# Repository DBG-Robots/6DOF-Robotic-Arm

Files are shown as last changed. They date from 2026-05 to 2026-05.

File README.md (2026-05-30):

# 6DOF Robotic Arm

A 6 degree-of-freedom robotic arm built from scratch. The project covers the full hardware and software stack: a custom STM32-based motor controller PCB, 3D-printed mechanical structure, and embedded firmware.

---

## Project Status

| Area | Status |
|---|---|
| Schematic | Complete |
| PCB Layout | In progress |
| STM32CubeMX pin assignment | Complete |
| Firmware | Not started |
| 3D Design | Not started |

---

## Repository Structure

```
.
├── LICENSE
├── PCB/
│   ├── Arm_Controller.kicad_sch       # Top-level schematic
│   ├── MCU.kicad_sch                  # STM32G431CBT6 schematic sheet
│   ├── Drivers.kicad_sch              # TMC2209 driver schematic sheet
│   ├── Power.kicad_sch                # Power supply schematic sheet
│   ├── Connectors.kicad_sch           # Connector schematic sheet
│   ├── Indicator.kicad_sch            # LED indicator schematic sheet
│   ├── Arm_Controller.kicad_pcb       # PCB layout
│   ├── Arm_Controller.kicad_pro       # KiCad project file
│   └── hardware/                      # Datasheets and reference material
└── STM32Cube/
    ├── Core/                          # Generated HAL application code
    ├── Drivers/                       # STM32 HAL and CMSIS drivers
    ├── EWARM/                         # IAR project files
    └── Robot Arm.ioc                  # STM32CubeMX configuration
```

---

## Hardware Overview

### Microcontroller — STM32G431CBT6

The board is centred around an STM32G431CBT6 in LQFP48 packaging, running at 170 MHz via PLL sourced from an 8 MHz external HSE crystal. USB uses the internal HSI48 oscillator via the CK48 mux to hit exactly 48 MHz without pulling the main PLL.

Flash latency is configured to `FLASH_LATENCY_4` as required at 170 MHz. The HAL timebase is moved from SysTick to TIM6 to avoid conflict with the USB stack.

SWD debug is available on PA13 (SWDIO) and PA14 (SWCLK).

### Stepper Motor Drivers — TMC2209

Six TMC2209 drivers handle the six stepper motor axes. Drivers are split into two banks of three, each sharing a UART line for configuration:

- **USART1 (PA9)** — Motors 1–3, half-duplex, 115200 baud
- **USART2 (PB3)** — Motors 4–6, half-duplex, 115200 baud

Up to three drivers share a single UART line using the TMC2209 address selection scheme via MS1/MS2 pins (addresses 0–3).

Each driver exposes a STEP input driven by hardware PWM (TIM2/TIM3 channels), a DIR GPIO, and a shared active-low enable line per bank (TMC_A_ENN, TMC_B_ENN). DIAG outputs from all six drivers are wired to EXTI lines 10–15 on PORTB for simultaneous independent fault interrupts.

Motor output pins (A1, A2, B1, B2 per driver) connect to 5 mm pitch screw terminals for direct stepper wiring.

Sense resistors are 0.11 Ω in 1206 package. Sustained motor current must not exceed 1.5 A per driver to stay within the 0.25 W resistor rating.

The TMC2209 accepts 4.75 V to 29 V on its motor supply. The 24 V rail is protected by a TVS diode clamping at ~29 V to keep transient spikes within this limit, particularly relevant when running from a 6S LiPo (max 25.2 V fully charged).

#### SPREAD Pin Configuration

Each driver has a dedicated 3-way solder jumper (`TMCX_SPREAD`) to select the chopper mode:

| SPREAD state | Mode |
|---|---|
| Pulled LOW (GND) | StealthChop2 — ultra-quiet operation |
| Pulled HIGH (3V3) | SpreadCycle — maximum torque |

Default: pulled HIGH (SpreadCycle). A 100 Ω series resistor is placed between the 3V3 rail and pad 1 of each jumper to limit current in the event of accidental full bridge.

> **Friendly Reminder:** Always have exactly ONE bridge between two pads! Keeping SPREAD floating will result in undefined behaviour and bridging all 3 pads will short GND and +3V3, resulting in a useless piece of green fiberglass. We do not take responsibility for this happening and recommend always testing for a short after resoldering these solder bridges.

### CAN Bus — FDCAN1 with ISO1042DWVR Isolator

CAN communication uses the STM32 FDCAN1 peripheral on PB8 (RX) and PB9 (TX), galvanically isolated via an ISO1042DWVR transceiver. The MCU side runs at 3.3 V; the bus side uses a 5 V isolated supply. Both supply pins carry decoupling capacitors close to the IC.

A 120 Ω termination resistor between CAN_H and CAN_L is present on the bus side, controlled by a solder bridge jumper (JP1). Close JP1 only if this board sits at a physical endpoint of the CAN bus. The default state is open.

> **Note:** JP1 default is OPEN. Exactly two 120 Ω terminations must be present across the entire CAN bus.

The ISO1042 is rated for CAN FD up to 5 Mbps. The board is currently configured for classic CAN. FDCAN timing parameters will need to be recalculated once SYSCLK is confirmed at 170 MHz.

> **TODO:** CAN bus connector footprint is `Connector_Molex:Molex_Pico-Lock_504050-0791_1x07-1MP_P1.50mm_Horizontal`. Exact pinout for the robot-side harness is not yet defined — document and lock this before PCB sign-off.

### Power System

Three 24 V power inputs feed the board via a shared pre-fuse node (`VBAT_IN`), then through a 15 A / 50 V fuse onto the protected `+24V` bus:

- **Robot power distribution board** — dedicated 2-pin connector. Protected by a Schottky diode (MBR1545, SMB package) so no current can ever flow back into the distribution board.
- **Battery** — XT60 female connector on-board, intended for 6S LiPo (22.2 V nominal, 25.2 V max fully charged). Protected by a Schottky diode in the same way.
- **J_PWR24V** — 2-pin 5 mm screw terminal. Accepts a standard 24 V DC supply or any external 24 V source. Also usable as a 24 V output tap. **No diode protection on this connector** — it connects directly to the `VBAT_IN` node ahead of the fuse. Polarity is marked clearly on silkscreen. Reverse polarity here will damage the board.

All three sources meet at `VBAT_IN` before the fuse, so all input current passes through fuse protection regardless of which source is used. Only one power source should be connected at a time.

> **Schottky diode note (MBR1545, D_SMB footprint):** Pin 1 = cathode, pin 2 = anode, pad 3 (thermal tab) = cathode. Pad 3 must be assigned the `VBAT_IN` net in KiCad — it is electrically the cathode and must not be left floating.

#### 24 V Rail Protection

The +24V bus carries decoupling and transient protection split across two locations — one cluster per driver bank — to minimise trace inductance to each group of three TMC2209s:

- A large electrolytic bulk capacitor (1000 µF / 50 V) placed centrally absorbs worst-case transients from all six drivers simultaneously
- Two ceramic capacitors (100 nF / 50 V, 0603) — one per driver bank cluster — handle high-frequency switching noise locally
- Two unidirectional TVS diodes (SMBJ26A) — one per driver bank cluster — clamp transients to protect the TMC2209 drivers, which have a 29 V absolute maximum rating

#### 3.3 V Regulation

Two separate paths supply the 3.3 V rail depending on power source. Both feed through a Schottky diode OR arrangement so neither source can back-feed the other.

**Buck converter (24 V → 3.3 V), used during normal operation:**

Placed in the top-right area of the board, drawing from the +24V bus. The buck converter output is nominally ~3.65 V. With approximately 0.30 V drop across the downstream Schottky diode at typical load, the STM32 VDD rail sits at approximately 3.35 V — within the 2.0 V–3.6 V operating range. The 3.3 V output trace crosses the power plane split boundary on layer 1 to reach the 3V3 plane region under the MCU.

**LDO (USB 5 V → 3.3 V), used during debug/programming only:**

Placed in the bottom-right area alongside the USB-C connector, minimising the VBUS trace length. The LDO output is 3.3 V. With the Schottky drop (~0.30 V at typical load), the STM32 VDD rail sits at approximately 3.0 V — still within the operating range, but marginal. USB power does not supply the motor drivers.

> If exactly 3.3 V is required at the MCU, replace the Schottky diode with an ideal diode circuit, or remove the debug USB power path entirely.

#### 3.3 V Rail Filtering

Given the noisy 24 V environment (6 switching stepper drivers), the 3.3 V rail carries additional filtering beyond a basic dev board:

- A ferrite bead at the rail entry point attenuates noise before it reaches any VDD decoupling
- A bulk reservoir capacitor handles load transients and converter lag
- Three 100 nF ceramics provide per-pin HF decoupling on VDD
- A second, higher-impedance ferrite bead further isolates the VDDA analog supply from VDD
- VDDA carries both a 100 nF and a 1 µF capacitor per ST's reference design
- VREF+ carries a 100 nF decoupling capacitor; a 0 Ω jumper allows VREF+ to be separated from VDDA if needed

### USB

Full-speed USB device on PA11 (DM) and PA12 (DP), clocked from HSI48. Intended for firmware flashing and debug only — does not power the motor drivers. USB-C connector placed bottom-right, adjacent to the LDO.

---

## PCB Layout

### Layer Stack

4-layer board:

| Layer | Use |
|---|---|
| 1 — Top copper | Signal and power routing |
| 2 — GND plane | Unbroken ground reference across the full board |
| 3 — Power plane | Split: 24 V under motor outputs and power section (U-shape), 3V3 under MCU and logic |
| 4 — Bottom copper | Signal routing |

The power plane split boundary runs between the motor-side pads and logic-side pads of each TMC2209 footprint. The GND plane is never split.

### Board Layout

The board follows a U-shaped topology with a central logic section:

- **Top edge** — Motors 4–6: screw terminals facing outward, TMC2209s below with 24 V side facing the edge and logic side facing inward
- **Bottom edge** — Motors 1–3: same orientation mirrored
- **Right-center** — Power input section: XT60 (VBAT), EXTN_PWR connector, J_PWR24V screw terminal, Schottky diodes D1/D2, fuse F1, bulk cap C13, ceramic caps and TVS diodes for each driver bank
- **Top-right** — 24 V → 3.3 V buck converter
- **Bottom-right** — USB-C connector and LDO (5 V → 3.3 V)
- **Center** — STM32G431CBT6, 3.3 V filtering, crystal, decoupling
- **Left edge** — CAN header and isolator (ISO1042DWVR), SWD debug header (J15), expansion headers, LED indicators

### Power Plane Notes

The 24 V plane covers the outer half of the board in a U-shape (top driver bank, power section, bottom driver bank). The 3.3 V plane occupies the inner-right region under the STM32, CAN isolator, and logic components. A copper-free gap separates the two regions; a single GND via stitch bridges them at one point to maintain a common ground reference without creating a loop.

All TMC2209 footprints are oriented so motor output pads (A1, A2, B1, B2) sit over the 24 V plane and logic pads (STEP, DIR, UART, DIAG) sit over the 3.3 V plane. The plane split line runs through the gap between these pad clusters on each driver.

---

## Pin Assignment

### STEP Outputs (Hardware PWM)

| Pin | Label | Timer Channel |
|---|---|---|
| PA0 | TMC1_STEP | TIM2_CH1 |
| PA1 | TMC2_STEP | TIM2_CH2 |
| PA6 | TMC3_STEP | TIM3_CH1 |
| PA7 | TMC4_STEP | TIM3_CH2 |
| PB0 | TMC5_STEP | TIM3_CH3 |
| PB1 | TMC6_STEP | TIM3_CH4 |

TIM2 and TIM3 run independently, allowing different step rates per motor bank.

### DIR Outputs (GPIO)

| Pin | Label |
|---|---|
| PA3 | M1_DIR |
| PA4 | M2_DIR |
| PA5 | M3_DIR |
| PB4 | M4_DIR |
| PB5 | M5_DIR |
| PB6 | M6_DIR |

Grouped by port to allow efficient single-register writes.

### Enable Outputs (Active LOW)

| Pin | Label | Controls |
|---|---|---|
| PA10 | TMC_A_ENN | Motors 1–3 |
| PA15 | TMC_B_ENN | Motors 4–6 |

Pulling both low implements a hardware e-stop across all six axes.

### DIAG Inputs (EXTI)

| Pin | Label | EXTI Line |
|---|---|---|
| PB10 | TMC1_DIAG | EXTI10 |
| PB11 | TMC2_DIAG | EXTI11 |
| PB12 | TMC3_DIAG | EXTI12 |
| PB13 | TMC4_DIAG | EXTI13 |
| PB14 | TMC5_DIAG | EXTI14 |
| PB15 | TMC6_DIAG | EXTI15 |

All DIAG lines sit on unique EXTI lines, so all six can fire simultaneously without arbitration. DIAG is driven HIGH by the TMC2209 on stall or fault detection.

### Indicators

| LED | Pin | Resistor | Color |
|---|---|---|---|
| STATUS_LED | PC13 | 1 kΩ | Red |
| POWER_LED | +3V3 (always-on) | 1.1 kΩ | Green |
| ACTIVITY_LED | PA8 | 390 Ω | Blue |

### Expansion Headers

| Pin | Use |
|---|---|
| PA2 | 3-pin 2.54 mm header (BTN/FAN/Thermistor) |
| PB2 | 3-pin 2.54 mm header (BTN/FAN) |
| PB7 | TIM4_CH2 — recommended for PWM fan control |

Headers are 3-pin 2.54 mm (GND / Signal / 3V3) with 10 kΩ pullup on the signal line for a defined state when unplugged.

PA2 is additionally suitable as a thermistor input (ADC) — the 10 kΩ pullup acts as the upper half of a voltage divider. Standard 10 kΩ NTC thermistors connect between the PA2 signal pad and GND.

---

## BOOT0 / PB8 — nBOOT_SEL Configuration

PB8 is shared between the FDCAN1_RX function and BOOT0. To free PB8 for CAN use permanently, the option byte **nBOOT_SEL = 1** must be programmed via STM32CubeProgrammer at first flash. This redirects boot mode selection away from the physical BOOT0 pin to the nBOOT0 option bit, which is set to 1 (normal boot from flash).

No physical BOOT or RESET button is fitted. NRST is accessible via pin 12 of the SWD header.

A test pad (TP_PB8) is placed on the PCB for two purposes:

1. Probing the CAN receive signal during bring-up.
2. Emergency bootloader recovery on boards where nBOOT_SEL was not programmed correctly — hold TP_PB8 HIGH at power-on to force the ROM bootloader via USB DFU.

---

## SWD Debug Header — J15

- Connector: 2×7 pin, 1.27 mm pitch, vertical through-hole
- KiCad footprint: `Connector_PinHeader_1.27mm:PinHeader_2x07_P1.27mm_Vertical`
- Pinout: STDC14 per ST UM2448 Table 6
- Preferred part: Samtec FTSH-107-01-L-DV-K-A (adds alignment shroud; any 2×7 1.27 mm header is electrically equivalent)
- Recommended debugger: **STLINK-V3MINIE** (ships with STDC14 ribbon cable)

| Pin | Signal |
|---|---|
| 1, 2 | Reserved — NC |
| 3 | T_VCC → +3V3 |
| 4 | SWDIO → PA13 |
| 5, 7 | GND |
| 6 | SWCLK → PA14 |
| 8 | SWO → NC (PB3 occupied by USART2) |
| 9 | NC |
| 10 | NC |
| 11 | GNDDetect → GND |
| 12 | NRST |
| 13, 14 | VCP RX/TX → NC |

---

## Test Points

All test points use 2.0 mm round pads for power rails and 1.0 mm round pads for signals, compatible with flying probe and pogo pin fixtures.

| Signal | Notes |
|---|---|
| GND | Power |
| +3V3 | Power |
| +24V | Power |
| VBUS | Power |
| CC1 | USB |
| CC2 | USB |
| TMC1–6 DIAG | One pad per driver |
| TMC1–6 INDEX | One pad per driver |
| TP_PB8 / BOOT0 | 1.5 mm round pad — CAN RX probe point and bootloader recovery |
| VDDA | Analog supply, after the VDDA ferrite bead |
| VREF+ | ADC reference rail |
| SWDIO | Debug |
| SWDCLK | Debug |
| NRST | Reset |
| CAN_H | Bus signal |
| CAN_L | Bus signal |
| CAN_GND | Bus ground reference |
| CAN_UART_TX | ISO1042 MCU-side TX |
| CAN_UART_RX | ISO1042 MCU-side RX |
| TMC_UART1 | USART1 half-duplex line (motors 1–3) |
| TMC_UART2 | USART2 half-duplex line (motors 4–6) |
| SW_NODE | Buck converter switching node — for scope noise analysis during bring-up |

---

## Known Issues and Open Items

- CAN connector pinout (Molex Pico-Lock 504050-0791) not yet defined for the robot-side harness.
- Connector for robot power distribution board not yet selected — footprint TBD.
- FDCAN timing parameters need recalculation after SYSCLK is confirmed at 170 MHz.
- PCB layout in progress — component placement largely complete, routing not yet started.
- Diode footprints (D1, D2): pad 3 (thermal tab) must be assigned `VBAT_IN` net in KiCad before routing.
- Buck converter and LDO placement pending final placement confirmation.
- Firmware not started.
- 3D mechanical design not started.

---

## Authorship

### 6DOF Robotic Arm — DBG-Robots

**Merlin Ortner**  
**Repository Owner & Principal Maintainer**  
Original author of this repository and responsible for long-term maintenance, development, and stewardship.  
Contact: ortnermerlin@gmail.com

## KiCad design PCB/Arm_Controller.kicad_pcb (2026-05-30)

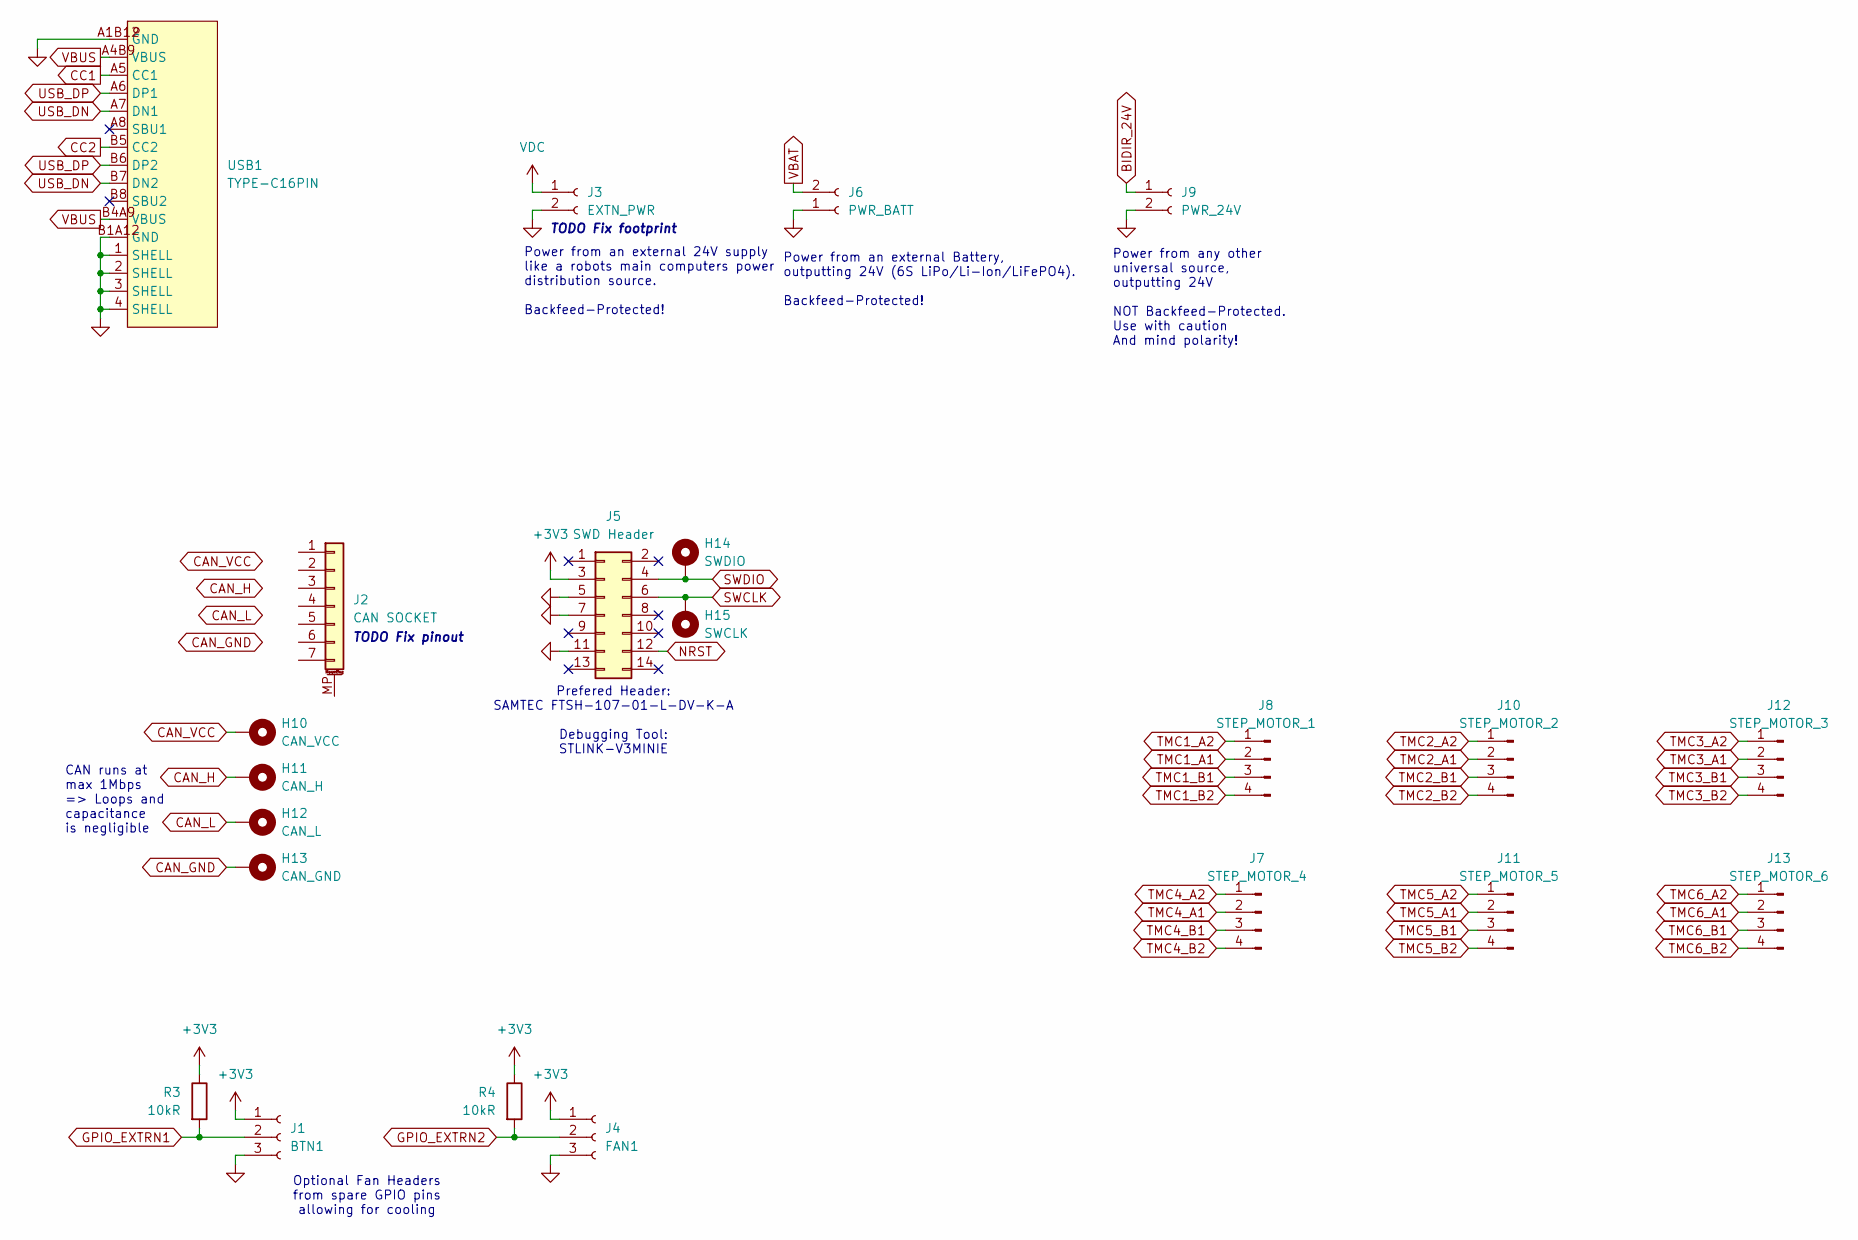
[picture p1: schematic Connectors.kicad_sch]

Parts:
H10: CAN_VCC; TestPoint_Pad_D2.0mm
H11: CAN_H; TestPoint_Pad_D1.0mm
H12: CAN_L; TestPoint_Pad_D1.0mm
H13: CAN_GND; TestPoint_Pad_D2.0mm
H14: SWDIO; TestPoint_Pad_D1.0mm
H15: SWCLK; TestPoint_Pad_D1.0mm
J1: BTN1; FanPinHeader_1x03_P2.54mm_Vertical
J2: CAN SOCKET; Molex_Pico-Lock_504050-0791_1x07-1MP_P1.50mm_Horizontal
J3: EXTN_PWR; Molex_SPOX_5267-02A_1x02_P2.50mm_Vertical
J4: FAN1; FanPinHeader_1x03_P2.54mm_Vertical
J5: SWD Header; PinHeader_2x07_P1.27mm_Vertical
J6: PWR_BATT; AMASS_XT60PW-F_1x02_P7.20mm_Horizontal
J7: STEP_MOTOR_4; TerminalBlock_Phoenix_MKDS-1,5-4-5.08_1x04_P5.08mm_Horizont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
J8: STEP_MOTOR_1; TerminalBlock_Phoenix_MKDS-1,5-4-5.08_1x04_P5.08mm_Horizont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
J9: PWR_24V; TerminalBlock_MaiXu_MX126-5.0-02P_1x02_P5.00mm
J10: STEP_MOTOR_2; TerminalBlock_Phoenix_MKDS-1,5-4-5.08_1x04_P5.08mm_Horizont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
J11: STEP_MOTOR_5; TerminalBlock_Phoenix_MKDS-1,5-4-5.08_1x04_P5.08mm_Horizont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
J12: STEP_MOTOR_3; TerminalBlock_Phoenix_MKDS-1,5-4-5.08_1x04_P5.08mm_Horizont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
J13: STEP_MOTOR_6; TerminalBlock_Phoenix_MKDS-1,5-4-5.08_1x04_P5.08mm_Horizont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
R3, R4: 10kR; R_0402_1005Metric
USB1: TYPE-C16PIN; USB-C-SMD_TYPE-C16PIN; MPN TYPE-C16PIN; LCSC Part C393939

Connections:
+3V3: J1.1, J4.1, J5.3, R3.1, R4.1; also elsewhere on the board
BIDIR_24V: J9.1; also elsewhere on the board
CAN_GND: H13.1 (1_1); also elsewhere on the board
CAN_H: H11.1 (1_1); also elsewhere on the board
CAN_L: H12.1 (1_1); also elsewhere on the board
CAN_VCC: H10.1 (1_1); also elsewhere on the board
CC1: USB1.A5 (CC1); also elsewhere on the board
CC2: USB1.B5 (CC2); also elsewhere on the board
GND: J1.3, J3.2, J4.3, J5.5, J5.7, J5.11, J6.1, J9.2, USB1.1 (SHELL), USB1.2 (SHELL), USB1.3 (SHELL), USB1.4 (SHELL), USB1.A1B12 (GND), USB1.B1A12 (GND); also elsewhere on the board
GPIO_EXTRN1: J1.2, R3.2; also elsewhere on the board
GPIO_EXTRN2: J4.2, R4.2; also elsewhere on the board
NRST: J5.12; also elsewhere on the board
SWCLK: H15.1 (1_1), J5.6; also elsewhere on the board
SWDIO: H14.1 (1_1), J5.4; also elsewhere on the board
TMC1_A1: J8.2; also elsewhere on the board
TMC1_A2: J8.1; also elsewhere on the board
TMC1_B1: J8.3; also elsewhere on the board
TMC1_B2: J8.4; also elsewhere on the board
TMC2_A1: J10.2; also elsewhere on the board
TMC2_A2: J10.1; also elsewhere on the board
TMC2_B1: J10.3; also elsewhere on the board
TMC2_B2: J10.4; also elsewhere on the board
TMC3_A1: J12.2; also elsewhere on the board
TMC3_A2: J12.1; also elsewhere on the board
TMC3_B1: J12.3; also elsewhere on the board
TMC3_B2: J12.4; also elsewhere on the board
TMC4_A1: J7.2; also elsewhere on the board
TMC4_A2: J7.1; also elsewhere on the board
TMC4_B1: J7.3; also elsewhere on the board
TMC4_B2: J7.4; also elsewhere on the board
TMC5_A1: J11.2; also elsewhere on the board
TMC5_A2: J11.1; also elsewhere on the board
TMC5_B1: J11.3; also elsewhere on the board
TMC5_B2: J11.4; also elsewhere on the board
TMC6_A1: J13.2; also elsewhere on the board
TMC6_A2: J13.1; also elsewhere on the board
TMC6_B1: J13.3; also elsewhere on the board
TMC6_B2: J13.4; also elsewhere on the board
USB_DN: USB1.A7 (DN1), USB1.B7 (DN2); also elsewhere on the board
USB_DP: USB1.A6 (DP1), USB1.B6 (DP2); also elsewhere on the board
VBAT: J6.2; also elsewhere on the board
VBUS: USB1.A4B9 (VBUS), USB1.B4A9 (VBUS); also elsewhere on the board
VDC: J3.1; also elsewhere on the board

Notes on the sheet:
TODO Fix footprint
Power from an external 24V supply like a robots main computers power distribution source. Backfeed-Protected!
Power from an external Battery, outputting 24V (6S LiPo/Li-Ion/LiFePO4). Backfeed-Protected!
CAN runs at max 1Mbps => Loops and capacitance is negligible
TODO Fix pinout
Prefered Header: SAMTEC FTSH-107-01-L-DV-K-A Debugging Tool: STLINK-V3MINIE
Optional Fan Headers from spare GPIO pins allowing for cooling
Power from any other universal source, outputting 24V NOT Backfeed-Protected. Use with caution And mind polarity!

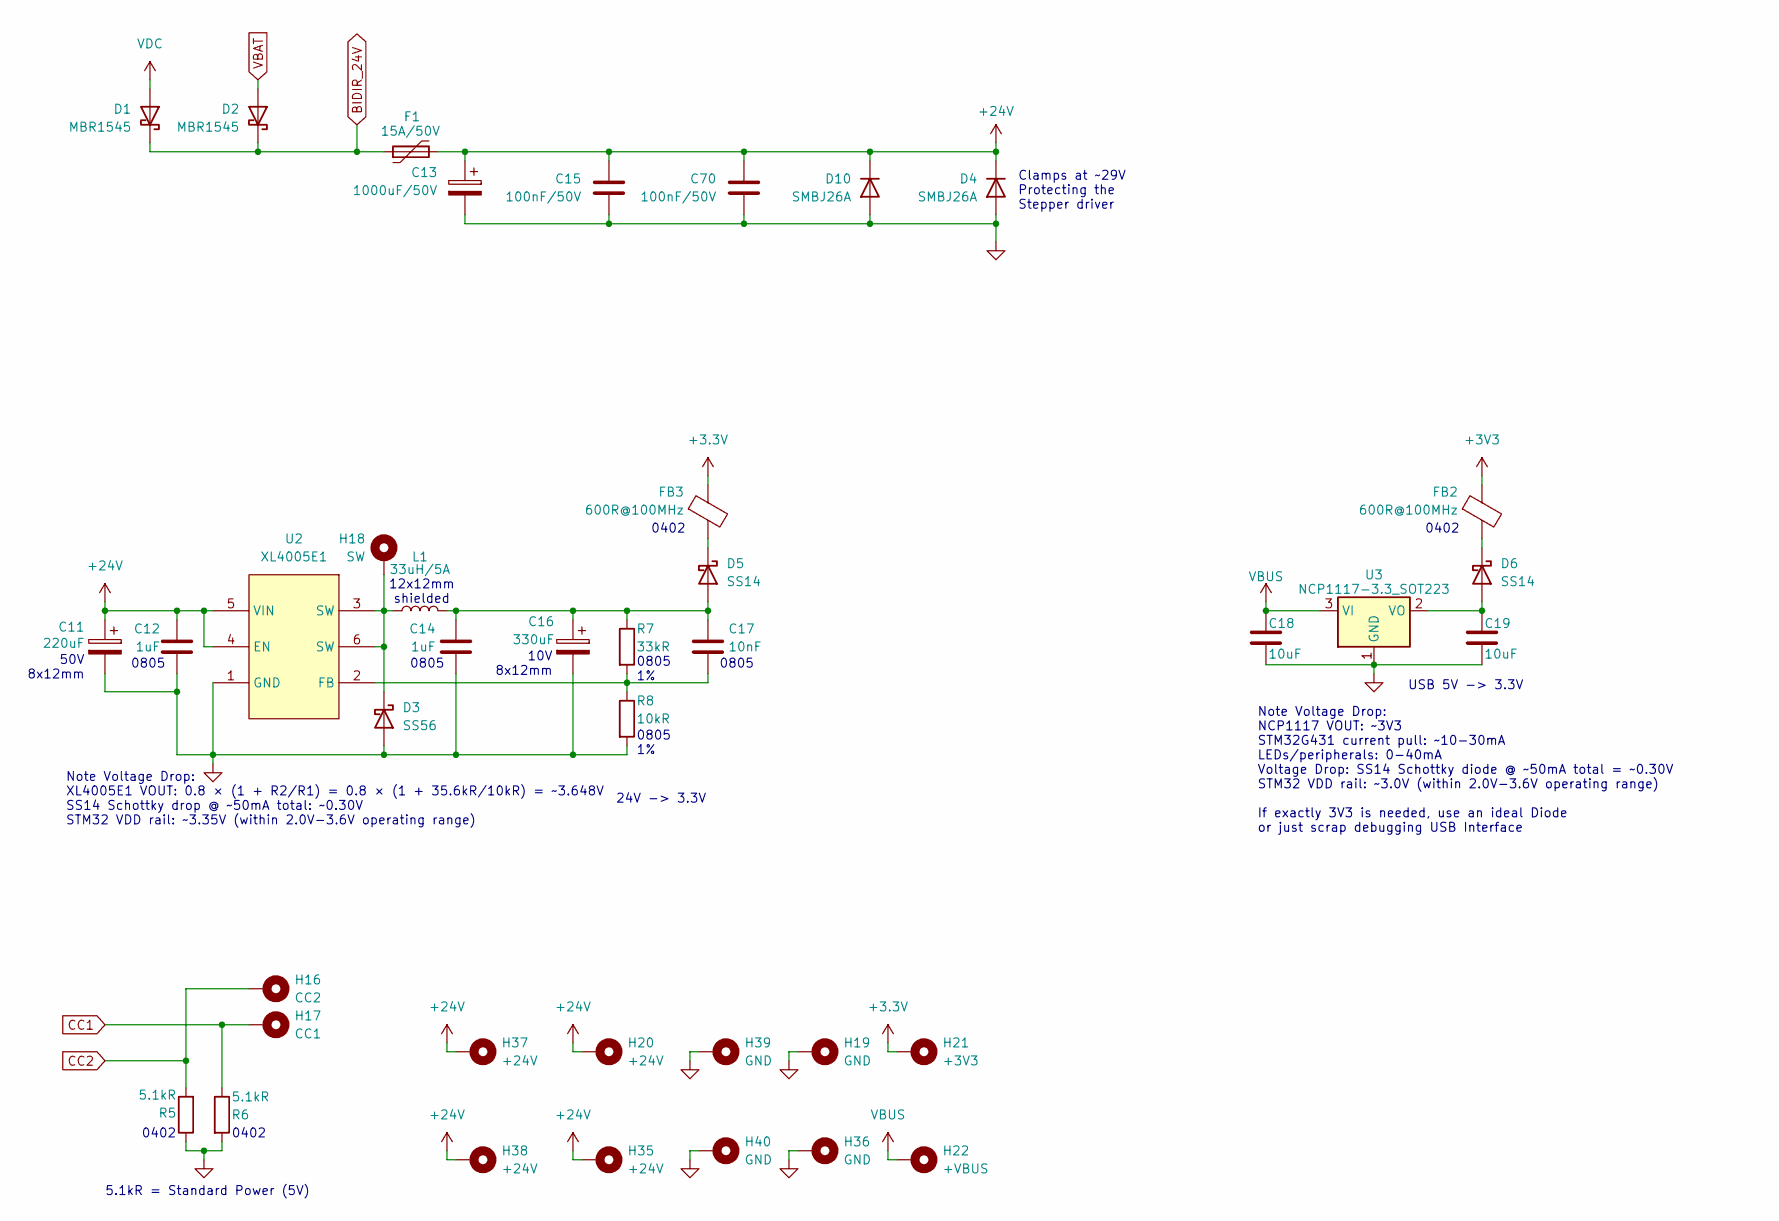
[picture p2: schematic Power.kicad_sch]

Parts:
C11: 220uF; CP_Radial_D8.0mm_P3.50mm
C12, C14: 1uF; C_0805_2012Metric
C13: 1000uF/50V; CP_Radial_D10.0mm_P5.00mm
C15, C70: 100nF/50V; C_0603_1608Metric
C16: 330uF; CP_Elec_8x10
C17: 10nF; C_0805_2012Metric
C18, C19: 10uF; C_0805_2012Metric
D1, D2: MBR1545; TO-263-2
D3: SS56; D_SMA
D4, D10: SMBJ26A; D_SMB
D5, D6: SS14; D_SMA
F1: 15A/50V; Fuseholder_Blade_ATO_Littelfuse_Pudenz_2_Pin
FB2, FB3: 600R@100MHz; L_0603_1608Metric
H16: CC2; TestPoint_Pad_D1.0mm
H17: CC1; TestPoint_Pad_D1.0mm
H18: SW; TestPoint_Pad_D1.0mm
H19, H36, H39, H40: GND; TestPoint_Pad_D2.0mm
H20, H35, H37, H38: +24V; TestPoint_Pad_D2.0mm
H21: +3V3; TestPoint_Pad_D2.0mm
H22: +VBUS; TestPoint_Pad_D2.0mm
L1: 33uH/5A; L_Bourns_SRR1260
R5, R6: 5.1kR; R_0402_1005Metric
R7: 33kR; R_0805_2012Metric
R8: 10kR; R_0805_2012Metric
U2: XL4005E1; TO-263-5_L10.2-W9.2-P1.70-TL; MPN XL4005E1; LCSC Part C73332
U3: NCP1117-3.3_SOT223; SOT-223-3_TabPin2

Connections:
+3.3V: FB3.1, H21.1 (1_1); also elsewhere on the board
+3V3: FB2.1; also elsewhere on the board
+24V: C11.1, C12.1, C13.1, C15.1, C70.1, D4.1 (K), D10.1 (K), F1.2, H20.1 (1_1), H35.1 (1_1), H37.1 (1_1), H38.1 (1_1), U2.4 (EN), U2.5 (VIN); also elsewhere on the board
BIDIR_24V: D1.1 (K), D2.1 (K), F1.1; also elsewhere on the board
CC1: H17.1 (1_1), R6.1; also elsewhere on the board
CC2: H16.1 (1_1), R5.2; also elsewhere on the board
GND: C11.2, C12.2, C13.2, C14.2, C15.2, C16.2, C18.2, C19.2, C70.2, D3.2 (A), D4.2 (A), D10.2 (A), H19.1 (1_1), H36.1 (1_1), H39.1 (1_1), H40.1 (1_1), R5.1, R6.2, R8.2, U2.1 (GND), U3.1 (GND); also elsewhere on the board
unnamed: D3.1 (K), H18.1 (1_1), L1.1, U2.3 (SW), U2.6 (SW)
unnamed: C14.1, C16.1, C17.1, D5.2 (A), L1.2, R7.1
unnamed: D5.1 (K), FB3.2
unnamed: C19.1, D6.2 (A), U3.2 (VO)
unnamed: D6.1 (K), FB2.2
unnamed: C17.2, R7.2, R8.1, U2.2 (FB)
VBAT: D2.2 (A); also elsewhere on the board
VBUS: C18.1, H22.1 (1_1), U3.3 (VI); also elsewhere on the board
VDC: D1.2 (A); also elsewhere on the board

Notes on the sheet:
0805
0805 1%
Clamps at ~29V Protecting the Stepper driver
10V 8x12mm
Note Voltage Drop: XL4005E1 VOUT: 0.8 × (1 + R2/R1) = 0.8 × (1 + 35.6kR/10kR) = ~3.648V SS14 Schottky drop @ ~50mA total: ~0.30V STM32 VDD rail: ~3.35V (within 2.0V-3.6V operating range)
USB 5V -> 3.3V
24V -> 3.3V
Note Voltage Drop: NCP1117 VOUT: ~3V3 STM32G431 current pull: ~10-30mA LEDs/peripherals: 0-40mA Voltage Drop: SS14 Schottky diode @ ~50mA total = ~0.30V STM32 VDD rail: ~3.0V (within 2.0V-3.6V operating range) If exactly 3V3 is needed, use an ideal Diode or just scrap debugging USB Interface
50V 8x12mm
5.1kR = Standard Power (5V)
0402
12x12mm shielded

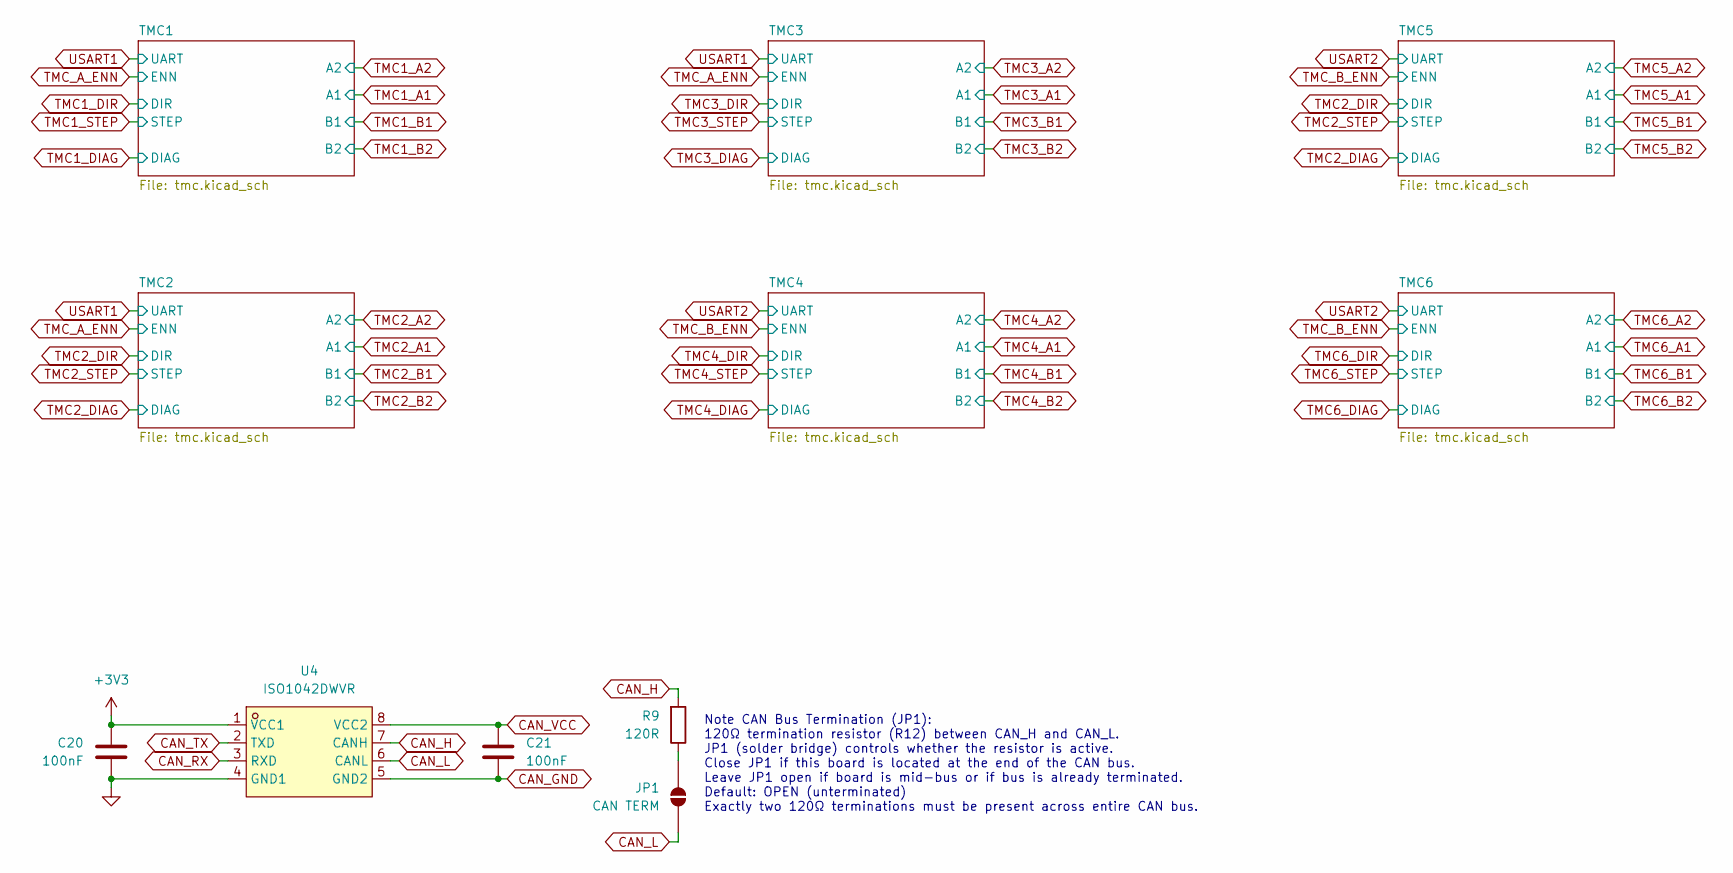
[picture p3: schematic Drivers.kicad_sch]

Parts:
C20, C21: 100nF; C_0402_1005Metric
JP1: CAN TERM; SolderJumper-2_P1.3mm_Open_RoundedPad1.0x1.5mm
R9: 120R; R_0402_1005Metric
U4: ISO1042DWVR; SOIC-8_L7.5-W5.9-P1.27-LS11.5-BL; MPN ISO1042DWVR; LCSC Part C2671714

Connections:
+3V3: C20.1, U4.1 (VCC1); also elsewhere on the board
CAN_GND: C21.2, U4.5 (GND2); also elsewhere on the board
CAN_H: R9.2, U4.7 (CANH); also elsewhere on the board
CAN_L: JP1.1 (A), U4.6 (CANL); also elsewhere on the board
CAN_RX: U4.3 (RXD); also elsewhere on the board
CAN_TX: U4.2 (TXD); also elsewhere on the board
CAN_VCC: C21.1, U4.8 (VCC2); also elsewhere on the board
GND: C20.2, U4.4 (GND1); also elsewhere on the board
unnamed: JP1.2 (B), R9.1

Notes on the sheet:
Note CAN Bus Termination (JP1): 120Ω termination resistor (R12) between CAN_H and CAN_L. JP1 (solder bridge) controls whether the resistor is active. Close JP1 if this board is located at the end of the CAN bus. Leave JP1 open if board is mid-bus or if bus is already terminated. Default: OPEN (unte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

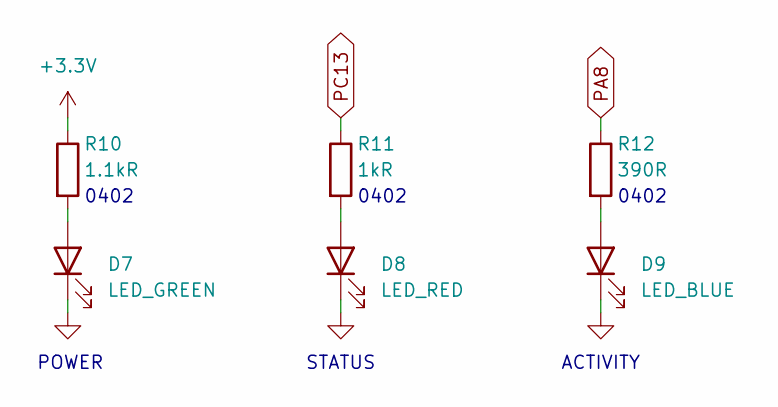
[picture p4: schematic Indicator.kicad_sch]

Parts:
D7: LED_GREEN; LED_0603_1608Metric
D8: LED_RED; LED_0603_1608Metric
D9: LED_BLUE; LED_0603_1608Metric
R10: 1.1kR; R_0402_1005Metric
R11: 1kR; R_0402_1005Metric
R12: 390R; R_0402_1005Metric

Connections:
+3.3V: R10.1; also elsewhere on the board
GND: D7.1 (K), D8.1 (K), D9.1 (K); also elsewhere on the board
unnamed: D7.2 (A), R10.2
unnamed: D8.2 (A), R11.2
unnamed: D9.2 (A), R12.2
PA8: R12.1; also elsewhere on the board
PC13: R11.1; also elsewhere on the board

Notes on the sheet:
POWER
0402
STATUS
ACTIVITY

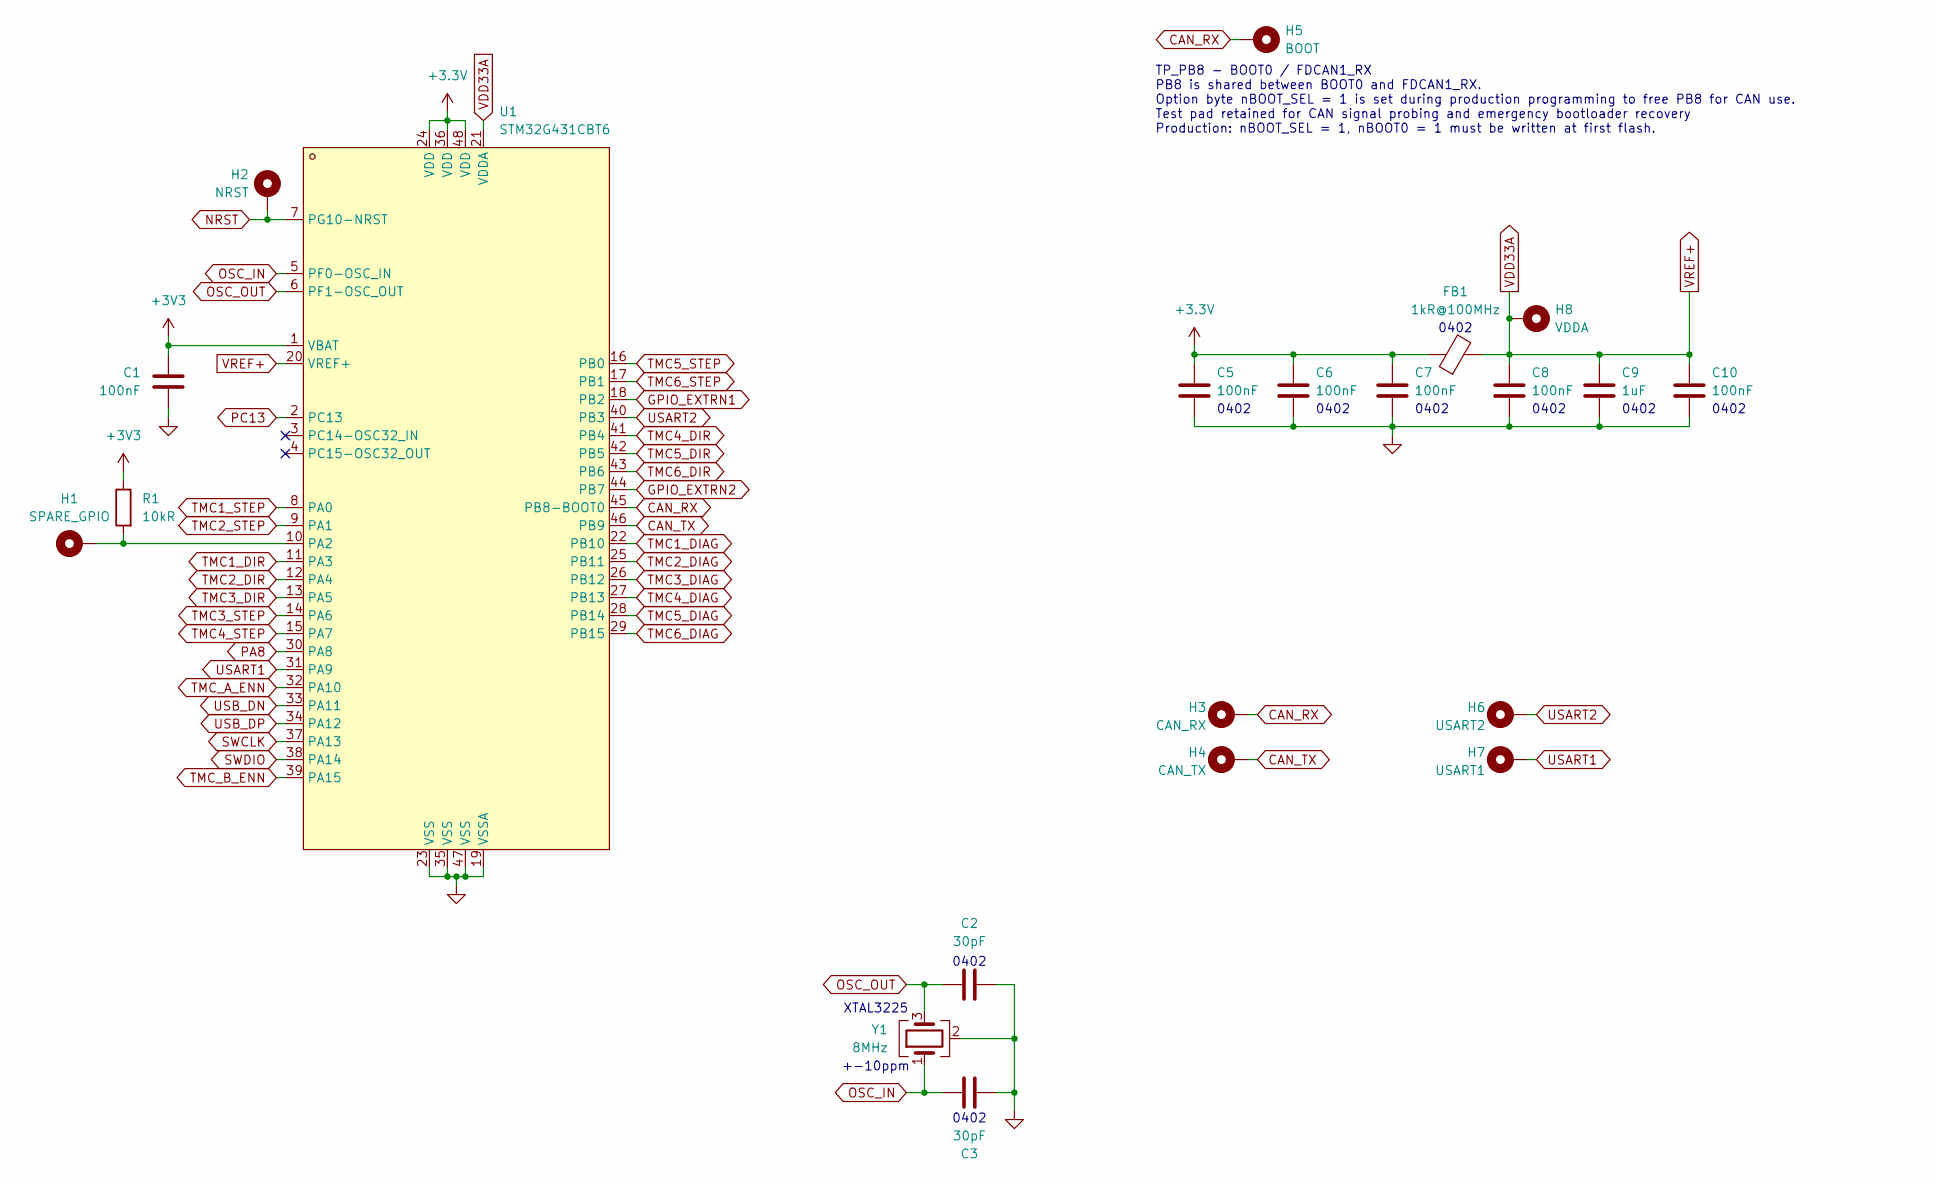
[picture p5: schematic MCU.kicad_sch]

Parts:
C1, C5, C6, C7, C8, C10: 100nF; C_0402_1005Metric
C2, C3: 30pF; C_0402_1005Metric
C9: 1uF; C_0402_1005Metric
FB1: 1kR@100MHz; L_0402_1005Metric
H1: SPARE_GPIO; TestPoint_Pad_D1.0mm
H2: NRST; TestPoint_Pad_D1.0mm
H3: CAN_RX; TestPoint_Pad_D1.0mm
H4: CAN_TX; TestPoint_Pad_D1.0mm
H5: BOOT; TestPoint_Pad_D1.0mm
H6: USART2; TestPoint_Pad_D1.0mm
H7: USART1; TestPoint_Pad_D1.0mm
H8: VDDA; TestPoint_Pad_D2.0mm
R1: 10kR; R_0402_1005Metric
U1: STM32G431CBT6; LQFP-48_L7.0-W7.0-P0.50-LS9.0-BL; MPN STM32G431CBT6; LCSC Part C529355
Y1: 8MHz; Crystal_SMD_3225-4Pin_3.2x2.5mm

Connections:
+3.3V: C5.1, C6.1, C7.1, FB1.1, U1.24 (VDD), U1.36 (VDD), U1.48 (VDD); also elsewhere on the board
+3V3: C1.1, R1.1, U1.1 (VBAT); also elsewhere on the board
CAN_RX: H3.1 (1_1), H5.1 (1_1), U1.45 (PB8-BOOT0); also elsewhere on the board
CAN_TX: H4.1 (1_1), U1.46 (PB9); also elsewhere on the board
GND: C1.2, C2.1, C3.2, C5.2, C6.2, C7.2, C8.2, C9.2, C10.2, U1.19 (VSSA), U1.23 (VSS), U1.35 (VSS), U1.47 (VSS), Y1.2 (G), Y1.4 (G); also elsewhere on the board
GPIO_EXTRN1: U1.18 (PB2); also elsewhere on the board
GPIO_EXTRN2: U1.44 (PB7); also elsewhere on the board
NRST: H2.1 (1_1), U1.7 (PG10-NRST); also elsewhere on the board
unnamed: H1.1 (1_1), R1.2, U1.10 (PA2)
OSC_IN: C3.1, U1.5 (PF0-OSC_IN), Y1.1
OSC_OUT: C2.2, U1.6 (PF1-OSC_OUT), Y1.3
PA8: U1.30 (PA8); also elsewhere on the board
PC13: U1.2 (PC13); also elsewhere on the board
SWCLK: U1.37 (PA13); also elsewhere on the board
SWDIO: U1.38 (PA14); also elsewhere on the board
TMC1_DIAG: U1.22 (PB10); also elsewhere on the board
TMC1_DIR: U1.11 (PA3); also elsewhere on the board
TMC1_STEP: U1.8 (PA0); also elsewhere on the board
TMC2_DIAG: U1.25 (PB11); also elsewhere on the board
TMC2_DIR: U1.12 (PA4); also elsewhere on the board
TMC2_STEP: U1.9 (PA1); also elsewhere on the board
TMC3_DIAG: U1.26 (PB12); also elsewhere on the board
TMC3_DIR: U1.13 (PA5); also elsewhere on the board
TMC3_STEP: U1.14 (PA6); also elsewhere on the board
TMC4_DIAG: U1.27 (PB13); also elsewhere on the board
TMC4_DIR: U1.41 (PB4); also elsewhere on the board
TMC4_STEP: U1.15 (PA7); also elsewhere on the board
TMC5_DIAG: U1.28 (PB14)
TMC5_DIR: U1.42 (PB5)
TMC5_STEP: U1.16 (PB0)
TMC6_DIAG: U1.29 (PB15); also elsewhere on the board
TMC6_DIR: U1.43 (PB6); also elsewhere on the board
TMC6_STEP: U1.17 (PB1); also elsewhere on the board
TMC_A_ENN: U1.32 (PA10); also elsewhere on the board
TMC_B_ENN: U1.39 (PA15); also elsewhere on the board
USART1: H7.1 (1_1), U1.31 (PA9); also elsewhere on the board
USART2: H6.1 (1_1), U1.40 (PB3); also elsewhere on the board
USB_DN: U1.33 (PA11); also elsewhere on the board
USB_DP: U1.34 (PA12); also elsewhere on the board
VDD33A: C8.1, C9.1, C10.1, FB1.2, H8.1 (1_1), U1.20 (VREF+), U1.21 (VDDA)

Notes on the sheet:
0402
XTAL3225 +-10ppm
TP_PB8 - BOOT0 / FDCAN1_RX PB8 is shared between BOOT0 and FDCAN1_RX. Option byte nBOOT_SEL = 1 is set during production programming to free PB8 for CAN use. Test pad retained for CAN signal probing and emergency bootloader recovery Production: nBOOT_SEL = 1, nBOOT0 = 1 must be written at first fla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

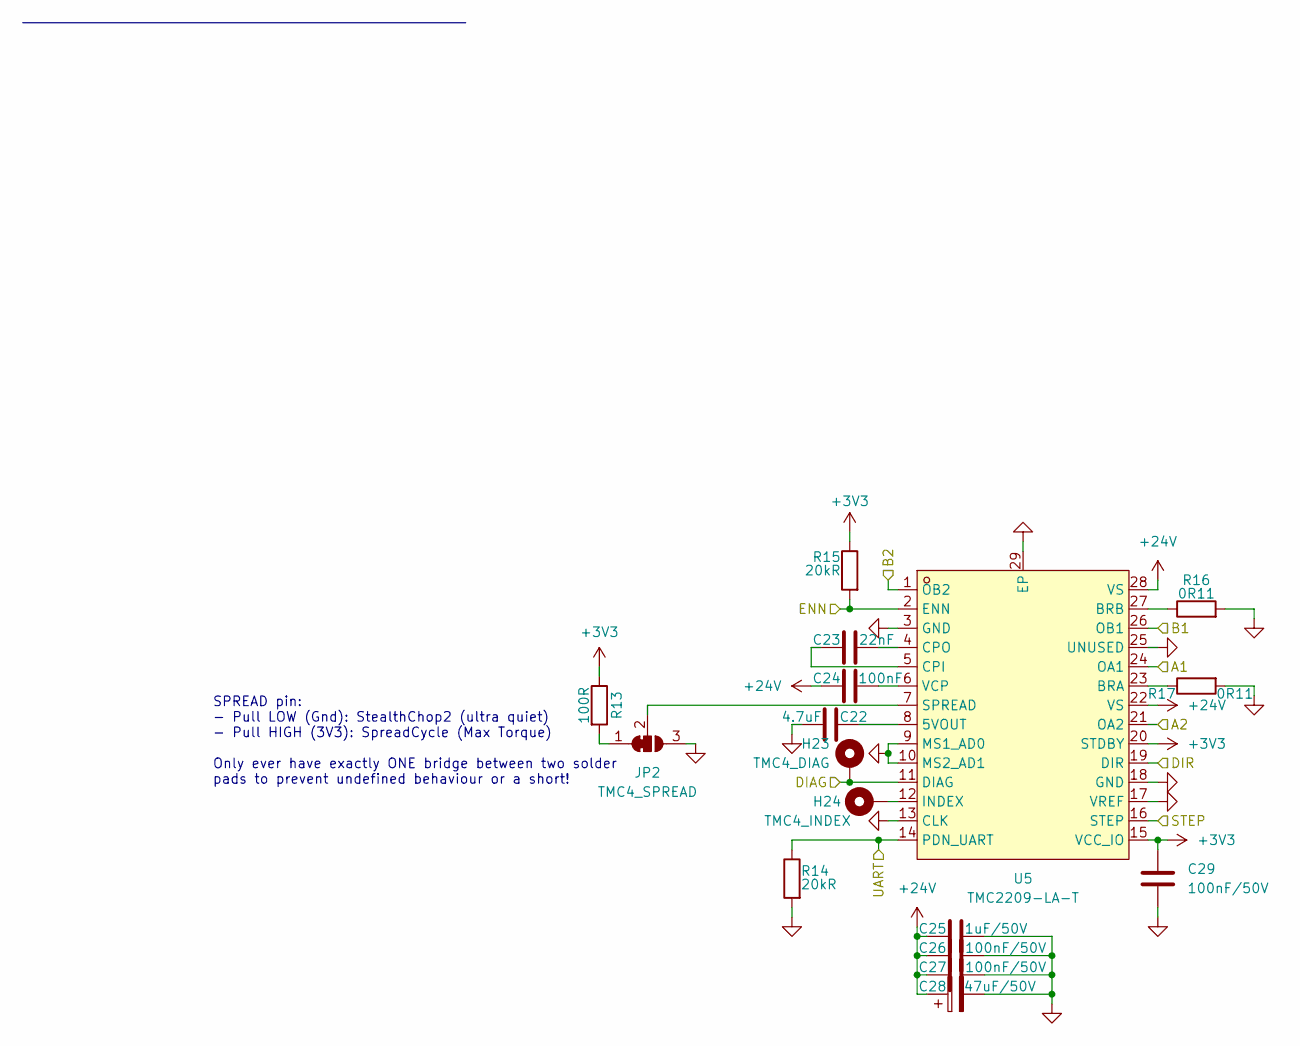
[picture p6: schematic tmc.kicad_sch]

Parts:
C22: 4.7uF; C_0805_2012Metric
C23: 22nF; C_0402_1005Metric
C24: 100nF; C_0402_1005Metric
C25: 1uF/50V; C_0603_1608Metric
C26, C27, C29: 100nF/50V; C_0402_1005Metric
C28: 47uF/50V; CP_Elec_8x10.5
H23: TMC4_DIAG; TestPoint_Pad_D1.0mm
H24: TMC4_INDEX; TestPoint_Pad_D1.0mm
JP2: TMC4_SPREAD; SolderJumper-3_P1.3mm_Bridged2Bar12_RoundedPad1.0x1.5mm
R13: 100R; R_0402_1005Metric
R14, R15: 20kR; R_0402_1005Metric
R16, R17: 0R11; R_1206_3216Metric
U5: TMC2209-LA-T; QFN-28_L5.0-W5.0-P0.50-BL-EP; MPN TMC2209-LA-T; LCSC Part C2150710

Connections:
+3V3: C29.1, R13.1, R15.1, U5.15 (VCC_IO), U5.20 (STDBY); also elsewhere on the board
+24V: C24.1, C25.1, C26.1, C27.1, C28.1, U5.22 (VS), U5.28 (VS); also elsewhere on the board
GND: C22.1, C25.2, C26.2, C27.2, C28.2, C29.2, JP2.3 (B), R14.2, R16.2, R17.2, U5.3 (GND), U5.9 (MS1_AD0), U5.10 (MS2_AD1), U5.13 (CLK), U5.17 (VREF), U5.18 (GND), U5.25 (UNUSED), U5.29 (EP); also elsewhere on the board
unnamed: JP2.1 (A), R13.2
unnamed: JP2.2 (C), U5.7 (SPREAD)
unnamed: C22.2, U5.8 (5VOUT)
unnamed: R17.1, U5.23 (BRA)
unnamed: R16.1, U5.27 (BRB)
unnamed: C23.1, U5.5 (CPI)
unnamed: C23.2, U5.4 (CPO)
unnamed: H24.1 (1_1), U5.12 (INDEX)
unnamed: C24.2, U5.6 (VCP)
TMC1_A1: U5.24 (OA1); also elsewhere on the board
TMC1_A2: U5.21 (OA2); also elsewhere on the board
TMC1_B1: U5.26 (OB1); also elsewhere on the board
TMC1_B2: U5.1 (OB2); also elsewhere on the board
TMC1_DIAG: H23.1 (1_1), U5.11 (DIAG); also elsewhere on the board
TMC1_DIR: U5.19 (DIR); also elsewhere on the board
TMC1_STEP: U5.16 (STEP); also elsewhere on the board
TMC_A_ENN: R15.2, U5.2 (ENN); also elsewhere on the board
USART1: R14.1, U5.14 (PDN_UART); also elsewhere on the board

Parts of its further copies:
C30, C38, C46, C54, C62: 4.7uF; C_0805_2012Metric
C31, C39, C47, C55, C63: 22nF; C_0402_1005Metric
C32, C40, C48, C56, C64: 100nF; C_0402_1005Metric
C33, C41, C49, C57, C65: 1uF/50V; C_0603_1608Metric
C34, C35, C37, C42, C43, C45, C50, C51, C53, C58, C59, C61, C66, C67, C69: 100nF/50V; C_0402_1005Metric
C36, C44, C52, C60, C68: 47uF/50V; CP_Elec_8x10.5
H25, H27, H29, H31, H33: TMC4_DIAG; TestPoint_Pad_D1.0mm
H26, H28, H30, H32, H34: TMC4_INDEX; TestPoint_Pad_D1.0mm
JP3, JP4, JP5, JP6, JP7: TMC4_SPREAD; SolderJumper-3_P1.3mm_Bridged2Bar12_RoundedPad1.0x1.5mm
R18, R23, R28, R33, R38: 100R; R_0402_1005Metric
R19, R20, R24, R25, R29, R30, R34, R35, R39, R40: 20kR; R_0402_1005Metric
R21, R22, R26, R27, R31, R32, R36, R37, R41, R42: 0R11; R_1206_3216Metric
U6, U7, U8, U9, U10: TMC2209-LA-T; QFN-28_L5.0-W5.0-P0.50-BL-EP; MPN TMC2209-LA-T; LCSC Part C2150710

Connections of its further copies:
+3V3: C37.1, C45.1, C53.1, C61.1, C69.1, R18.1, R20.1, R23.1, R25.1, R28.1, R30.1, R33.1, R35.1, R38.1, R40.1, U6.15 (VCC_IO), U6.20 (STDBY), U7.15 (VCC_IO), U7.20 (STDBY), U8.15 (VCC_IO), U8.20 (STDBY), U9.15 (VCC_IO), U9.20 (STDBY), U10.15 (VCC_IO), U10.20 (STDBY); also elsewhere on the board
+24V: C32.1, C33.1, C34.1, C35.1, C36.1, C40.1, C41.1, C42.1, C43.1, C44.1, C48.1, C49.1, C50.1, C51.1, C52.1, C56.1, C57.1, C58.1, C59.1, C60.1, C64.1, C65.1, C66.1, C67.1, C68.1, U6.22 (VS), U6.28 (VS), U7.22 (VS), U7.28 (VS), U8.22 (VS), U8.28 (VS), U9.22 (VS), U9.28 (VS), U10.22 (VS), U10.28 (VS); also elsewhere on the board
GND: C30.1, C33.2, C34.2, C35.2, C36.2, C37.2, C38.1, C41.2, C42.2, C43.2, C44.2, C45.2, C46.1, C49.2, C50.2, C51.2, C52.2, C53.2, C54.1, C57.2, C58.2, C59.2, C60.2, C61.2, C62.1, C65.2, C66.2, C67.2, C68.2, C69.2, JP3.3 (B), JP4.3 (B), JP5.3 (B), JP6.3 (B), JP7.3 (B), R19.2, R21.2, R22.2, R24.2, R26.2, R27.2, R29.2, R31.2, R32.2, R34.2, R36.2, R37.2, R39.2, R41.2, R42.2, U6.3 (GND), U6.9 (MS1_AD0), U6.10 (MS2_AD1), U6.13 (CLK), U6.17 (VREF), U6.18 (GND), U6.25 (UNUSED), U6.29 (EP), U7.3 (GND), U7.9 (MS1_AD0), U7.10 (MS2_AD1), U7.13 (CLK), U7.17 (VREF), U7.18 (GND), U7.25 (UNUSED), U7.29 (EP), U8.3 (GND), U8.9 (MS1_AD0), U8.10 (MS2_AD1), U8.13 (CLK), U8.17 (VREF), U8.18 (GND), U8.25 (UNUSED), U8.29 (EP), U9.3 (GND), U9.9 (MS1_AD0), U9.10 (MS2_AD1), U9.13 (CLK), U9.17 (VREF), U9.18 (GND), U9.25 (UNUSED), U9.29 (EP), U10.3 (GND), U10.9 (MS1_AD0), U10.10 (MS2_AD1), U10.13 (CLK), U10.17 (VREF), U10.18 (GND), U10.25 (UNUSED), U10.29 (EP); also elsewhere on the board
unnamed: JP3.1 (A), R18.2
unnamed: JP3.2 (C), U6.7 (SPREAD)
unnamed: JP4.1 (A), R23.2
unnamed: JP4.2 (C), U7.7 (SPREAD)
unnamed: JP5.1 (A), R28.2
unnamed: JP5.2 (C), U8.7 (SPREAD)
unnamed: JP6.1 (A), R33.2
unnamed: JP6.2 (C), U9.7 (SPREAD)
unnamed: JP7.1 (A), R38.2
unnamed: JP7.2 (C), U10.7 (SPREAD)
unnamed: C30.2, U6.8 (5VOUT)
unnamed: R22.1, U6.23 (BRA)
unnamed: R21.1, U6.27 (BRB)
unnamed: C31.1, U6.5 (CPI)
unnamed: C31.2, U6.4 (CPO)
unnamed: H26.1 (1_1), U6.12 (INDEX)
unnamed: C32.2, U6.6 (VCP)
unnamed: C38.2, U7.8 (5VOUT)
unnamed: R27.1, U7.23 (BRA)
unnamed: R26.1, U7.27 (BRB)
unnamed: C39.1, U7.5 (CPI)
unnamed: C39.2, U7.4 (CPO)
unnamed: H28.1 (1_1), U7.12 (INDEX)
unnamed: C40.2, U7.6 (VCP)
unnamed: C46.2, U8.8 (5VOUT)
unnamed: R32.1, U8.23 (BRA)
unnamed: R31.1, U8.27 (BRB)
unnamed: C47.1, U8.5 (CPI)
unnamed: C47.2, U8.4 (CPO)
unnamed: H30.1 (1_1), U8.12 (INDEX)
unnamed: C48.2, U8.6 (VCP)
unnamed: C54.2, U9.8 (5VOUT)
unnamed: R37.1, U9.23 (BRA)
unnamed: R36.1, U9.27 (BRB)
unnamed: C55.1, U9.5 (CPI)
unnamed: C55.2, U9.4 (CPO)
unnamed: H32.1 (1_1), U9.12 (INDEX)
unnamed: C56.2, U9.6 (VCP)
unnamed: C62.2, U10.8 (5VOUT)
unnamed: R42.1, U10.23 (BRA)
unnamed: R41.1, U10.27 (BRB)
unnamed: C63.1, U10.5 (CPI)
unnamed: C63.2, U10.4 (CPO)
unnamed: H34.1 (1_1), U10.12 (INDEX)
unnamed: C64.2, U10.6 (VCP)
TMC2_A1: U6.24 (OA1); also elsewhere on the board
TMC2_A2: U6.21 (OA2); also elsewhere on the board
TMC2_B1: U6.26 (OB1); also elsewhere on the board
TMC2_B2: U6.1 (OB2); also elsewhere on the board
TMC2_DIAG: H25.1 (1_1), H31.1 (1_1), U6.11 (DIAG), U9.11 (DIAG); also elsewhere on the board
TMC2_DIR: U6.19 (DIR), U9.19 (DIR); also elsewhere on the board
TMC2_STEP: U6.16 (STEP), U9.16 (STEP); also elsewhere on the board
TMC3_A1: U7.24 (OA1); also elsewhere on the board
TMC3_A2: U7.21 (OA2); also elsewhere on the board
TMC3_B1: U7.26 (OB1); also elsewhere on the board
TMC3_B2: U7.1 (OB2); also elsewhere on the board
TMC3_DIAG: H27.1 (1_1), U7.11 (DIAG); also elsewhere on the board
TMC3_DIR: U7.19 (DIR); also elsewhere on the board
TMC3_STEP: U7.16 (STEP); also elsewhere on the board
TMC4_A1: U8.24 (OA1); also elsewhere on the board
TMC4_A2: U8.21 (OA2); also elsewhere on the board
TMC4_B1: U8.26 (OB1); also elsewhere on the board
TMC4_B2: U8.1 (OB2); also elsewhere on the board
TMC4_DIAG: H29.1 (1_1), U8.11 (DIAG); also elsewhere on the board
TMC4_DIR: U8.19 (DIR); also elsewhere on the board
TMC4_STEP: U8.16 (STEP); also elsewhere on the board
TMC5_A1: U9.24 (OA1); also elsewhere on the board
TMC5_A2: U9.21 (OA2); also elsewhere on the board
TMC5_B1: U9.26 (OB1); also elsewhere on the board
TMC5_B2: U9.1 (OB2); also elsewhere on the board
TMC6_A1: U10.24 (OA1); also elsewhere on the board
TMC6_A2: U10.21 (OA2); also elsewhere on the board
TMC6_B1: U10.26 (OB1); also elsewhere on the board
TMC6_B2: U10.1 (OB2); also elsewhere on the board
TMC6_DIAG: H33.1 (1_1), U10.11 (DIAG); also elsewhere on the board
TMC6_DIR: U10.19 (DIR); also elsewhere on the board
TMC6_STEP: U10.16 (STEP); also elsewhere on the board
TMC_A_ENN: R20.2, R25.2, U6.2 (ENN), U7.2 (ENN); also elsewhere on the board
TMC_B_ENN: R30.2, R35.2, R40.2, U8.2 (ENN), U9.2 (ENN), U10.2 (ENN); also elsewhere on the board
USART1: R19.1, R24.1, U6.14 (PDN_UART), U7.14 (PDN_UART); also elsewhere on the board
USART2: R29.1, R34.1, R39.1, U8.14 (PDN_UART), U9.14 (PDN_UART), U10.14 (PDN_UART); also elsewhere on the board

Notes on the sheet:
SPREAD pin: - Pull LOW (Gnd): StealthChop2 (ultra quiet) - Pull HIGH (3V3): SpreadCycle (Max Torque) Only ever have exactly ONE bridge between two solder pads to prevent undefined behaviour or a short!

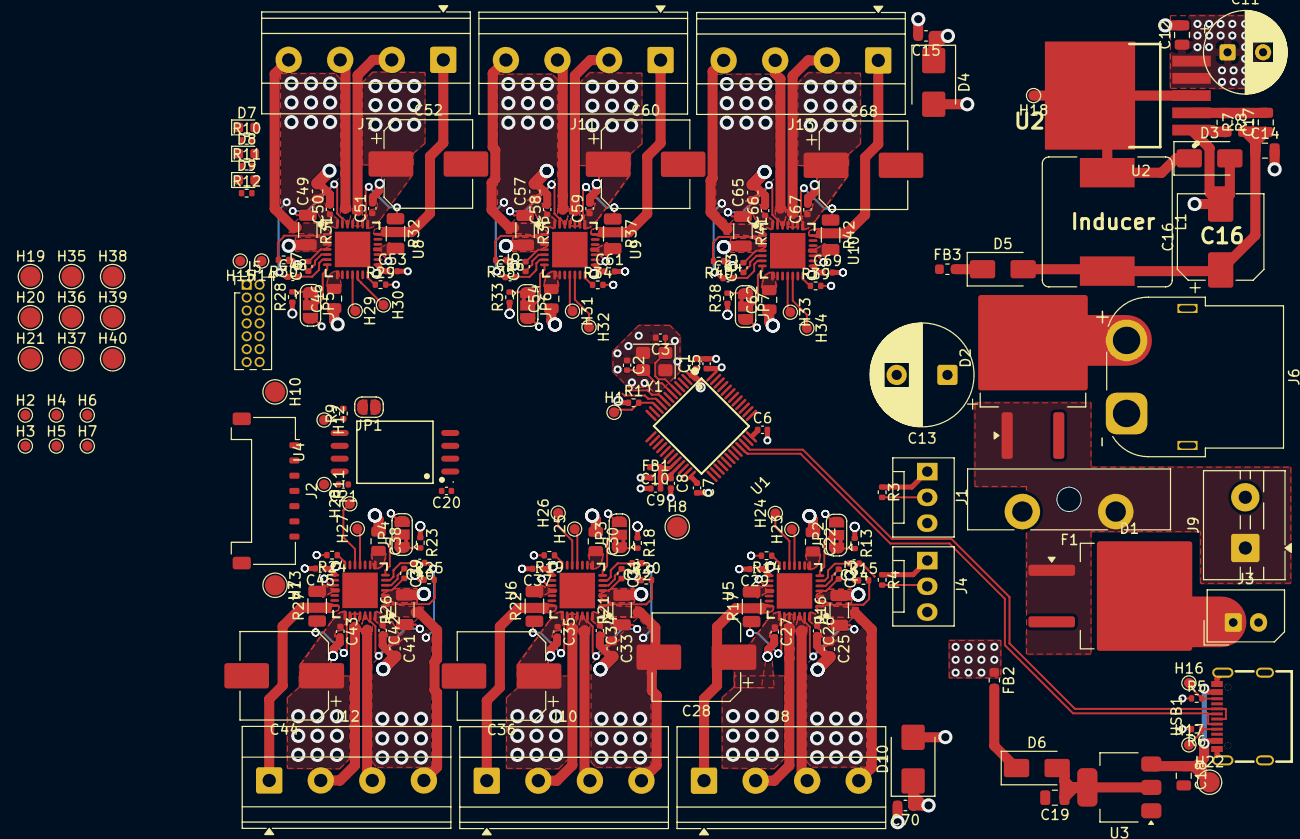
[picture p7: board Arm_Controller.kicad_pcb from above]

Board: 4 copper layers, 196 parts (0 on the bottom side), 136 nets.

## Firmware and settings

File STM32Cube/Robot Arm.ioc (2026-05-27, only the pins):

Mcu.UserName=STM32G431CBTx
PA0.GPIO_Label=TMC1_STEP
PA0.Signal=S_TIM2_CH1
PA1.GPIO_Label=TMC2_STEP
PA1.Signal=S_TIM2_CH2
PA10.Signal=GPIO_Output
PA11.Signal=USB_DM
PA12.Signal=USB_DP
PA13.Signal=SYS_JTMS-SWDIO
PA14.Signal=SYS_JTCK-SWCLK
PA15.Signal=GPIO_Output
PA3.GPIO_Label=TMC1_DIR
PA3.Signal=GPIO_Output
PA4.GPIO_Label=TMC1_DIR
PA4.Signal=GPIO_Output
PA5.GPIO_Label=TMC3_DIR
PA5.Signal=GPIO_Output
PA6.GPIO_Label=TMC3_STEP
PA6.Signal=S_TIM3_CH1
PA7.GPIO_Label=TMC4_STEP
PA7.Signal=S_TIM3_CH2
PA8.GPIO_Label=LED_ACT
PA8.Signal=GPIO_Output
PA9.Signal=USART1_TX
PB0.GPIO_Label=TMC5_STEP
PB0.Signal=S_TIM3_CH3
PB1.GPIO_Label=TMC6_STEP
PB1.Signal=S_TIM3_CH4
PB10.GPIO_Label=TMC1_DIAG
PB10.Signal=GPIO_Input
PB11.GPIO_Label=TMC2_DIAG
PB11.Signal=GPIO_Input
PB12.GPIO_Label=TMC3_DIAG
PB12.Signal=GPIO_Input
PB13.GPIO_Label=TMC4_DIAG
PB13.Signal=GPIO_Input
PB14.GPIO_Label=TMC5_DIAG
PB14.Signal=GPIO_Input
PB15.GPIO_Label=TMC5_DIAG
PB15.Signal=GPIO_Input
PB3.Signal=USART2_TX
PB4.GPIO_Label=TMC4_DIR
PB4.Signal=GPIO_Output
PB5.GPIO_Label=TMC5_DIR
PB5.Signal=GPIO_Output
PB6.GPIO_Label=TMC6_DIR
PB6.Signal=GPIO_Output
PB8-BOOT0.Signal=FDCAN1_RX
PB9.Signal=FDCAN1_TX
PC13.GPIO_Label=LED_STAT
PC13.Signal=GPIO_Output
PF0-OSC_IN.Signal=RCC_OSC_IN
PF1-OSC_OUT.Signal=RCC_OSC_OUT

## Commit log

2026-05-27 Added STM32Cube Project
2026-05-27 Revise README for 6DOF Robotic Arm project
    Updated project title and added detailed project overview, status, repository structure, hardware overview, pin assignments, and known issues.
2026-05-27 Minor Schematic tweaks like - Adding pull up resistors to the spare GPIO pins - Renaming some Global Labels - Labeling all the pins on the STM32 correctly
    [Arm_Controller.kicad_sch, Connectors.kicad_sch, MCU.kicad_sch]
2026-05-27 Improved Protection and Board Testability - Added power rail protection and decoupling for stepper motor noise environment - Added TVS, bulk caps and fuse upgrade on 24V rail - Added test pads for br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
    [Arm_Controller.kicad_pcb, Connectors.kicad_sch, Drivers.kicad_sch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]
2026-05-27 Enhance clarity and detail in README.md
    Updated README.md to improve clarity and detail in various sections, including motor output connections, power inputs, and test points.
2026-05-28 PCB Layout: Initial TMC2209 driver cluster layout
    - Defined netclasses for 24V, Stepper Motor, 3V3, 5V and Signal
    - Decided on 4-layer stackup: Signal / GND / Power / Signal
    - Routed high current motor output traces with tapered zone fills
    - Placed and routed VS decoupling caps (100nF, 1uF, 47uF electrolytic)
    - Routed sense resistors with dedicated GND vias per resistor
    - Routed BRA/BRB via bottom layer with perpendicular crossing under motor traces
    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
    [Arm_Controller.kicad_pcb, Connectors.kicad_sch, Drivers.kicad_sch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]
2026-05-28 Started laying out the PCB - Decided for a square-shaped board - Split Motor Controllers on top and bottom - Split Power Plane (+3V3 on logic side, +24V on motor side) - Roughly layed out the board e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
    [Arm_Controller.kicad_pcb, Connectors.kicad_sch, Drivers.kicad_sch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]
2026-05-30 Continued PCB Development - Routed MCU decoupeling and Isolated Crystal - Routed LDO Buck converter (VBUS (+5V) -> +3V3) - Routed Buck Converter (+24V -> +3V3) needs review (U2-pin1-GND) - Started Ro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
    [Arm_Controller.kicad_pcb, Connectors.kicad_sch, Drivers.kicad_sch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]
